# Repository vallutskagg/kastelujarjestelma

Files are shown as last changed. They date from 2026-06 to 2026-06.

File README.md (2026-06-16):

# Watering System

ESP32- ja ESP-IDF-pohjainen automaattinen kastelujärjestelmä. Järjestelmä
mittaa maan kosteutta ja ulkolämpötilaa, tarkkailee vesisäiliön tasoa ja ohjaa
vesipumppua releen kautta. Mittaus- ja ohjaustiedot välitetään MQTT:lla.

Tämä README sisältää kokoamis-, asennus-, kalibrointi-, käyttö- ja
GitHub-ohjeet, joiden avulla toinen käyttäjä voi ottaa projektin käyttöön.

## Sisältö

- [Toimintaperiaate](#toimintaperiaate)
- [Tarvittavat osat](#tarvittavat-osat)
- [Kytkennät](#kytkennät)
- [Ohjelmiston asennus](#ohjelmiston-asennus)
- [Asetukset](#asetukset)
- [Kalibrointi](#kalibrointi)
- [MQTT-käyttö](#mqtt-käyttö)
- [Testaus](#testaus)
- [PCB- ja kotelotiedostot](#pcb--ja-kotelotiedostot)
- [Vianhaku](#vianhaku)

## Toimintaperiaate

ESP32 suorittaa seuraavaa toimintalogiikkaa:

1. Laite käynnistää releen pois päältä, alustaa anturit ja yhdistää 2,4 GHz
   Wi-Fi-verkkoon sekä MQTT-brokeriin.
2. Maankosteusanturista luetaan useita ADC-näytteitä ja niiden keskiarvo.
3. Jos ADC-arvo ylittää kuivuusrajan riittävän monta peräkkäistä kertaa, maa
   tulkitaan kuivaksi.
4. Pumppu käynnistetään vain, jos pumpun ohjaus on sallittu, kastelujen välinen
   turva-aika on kulunut ja säiliöanturi ei ilmoita veden olevan vähissä.
5. Pumppu käy asetetun ajan ja sammuu automaattisesti.
6. DS18B20-lämpötila, maankosteus, säiliön tila ja pumpun tila julkaistaan
   MQTT:lla.
7. Pumppua, mittausta ja kasteluaikaa voi ohjata myös MQTT-komennoilla.

Säiliön tila `LOW` estää sekä automaattisen että manuaalisen pumppauksen.
Tila `UNKNOWN` ei nykyisessä ohjelmassa estä pumppausta. Jos säiliöanturi ei ole
kytketty tai toimii väärin, pumppua saa käyttää vain valvotusti.

Releohjaus on active-low:

- `GPIO26 = HIGH`: rele ja pumppu pois päältä
- `GPIO26 = LOW`: rele ja pumppu päällä

Kastelujen välinen turva-aika tallennetaan vain ESP32:n muistiin. Laitteen
uudelleenkäynnistys nollaa viimeisen kastelun ajan.

## Projektin rakenne

| Polku | Sisältö |
| --- | --- |
| [`main/`](main/) | ESP32-ohjelmiston lähdekoodi ja asetukset |
| [`hardware/pcb/`](hardware/pcb/) | KiCad-projekti ja piirilevyn lähdetiedostot |
| [`hardware/enclosure/`](hardware/enclosure/) | OpenSCAD-kotelomalli |
| [`PCB_OHJE.md`](PCB_OHJE.md) | PCB:n yksityiskohtaiset suunnitteluohjeet |
| [`GITHUB_OHJE.md`](GITHUB_OHJE.md) | Git- ja GitHub-työskentelyohje |
| `pump_test_values_backup_2026-04-10.txt` | Aiemmat pumpun testiasetukset |

## Tarvittavat osat

Pakolliset osat:

- ESP32 DevKit, jota ESP-IDF tukee
- kapasitiivinen maankosteusanturi, analoginen `0-3,0 V` ulostulo
- active-low-yhteensopiva 1-kanavainen 5 V relemoduuli
- 3-5 V DC-vesipumppu ja sopiva letku
- kapasitiivinen säiliön tasoanturi digitaalisella ulostulolla
- virtalähde pumpulle ja releelle
- johdot ja liittimet

Suositellut tai valinnaiset osat:

- DS18B20-lämpötila-anturi
- `4,7 kOhm` vastus DS18B20 DATA-linjan ja `3V3`:n väliin
- LED ja `330 Ohm` sarjavastus säiliön alhaisen tason ilmaisimeksi
- `100 nF` ohituskondensaattorit antureiden syöttöihin
- projektin KiCad-piirilevy ja 3D-tulostettu kotelo

Katso tarkempi komponentti- ja liitinluettelo tiedostosta
[`PCB_OHJE.md`](PCB_OHJE.md).

## Kytkennät

### ESP32-signaalit

| Toiminto | ESP32-pinni | Huomio |
| --- | --- | --- |
| Releen ohjaus | `GPIO26` | Active-low |
| Maankosteusanturin AO | `GPIO34` | ADC1 channel 6, enintään 3,3 V |
| DS18B20 DATA | `GPIO4` | `4,7 kOhm` pull-up vastus `3V3`:een |
| Säiliön tasoanturin signaali | `GPIO27` | Oletuksena HIGH tarkoittaa vettä |
| Säiliön tason LED | `GPIO25` | Oletuksena LED syttyy, kun säiliö on LOW |

### Peruskytkentä

- Kytke ESP32:n, relemoduulin, antureiden ja pumpun virtalähteen maat yhteen.
- Kytke maankosteusanturi `3V3`:een. Älä syötä yli 3,3 V signaalia
  `GPIO34`:aan.
- Kytke DS18B20 `3V3`:een ja lisää DATA-linjalle `4,7 kOhm` pull-up-vastus.
- Kytke relemoduulin `IN` pinniin `GPIO26`.
- Kytke pumpun virtapiiri releen `COM`- ja `NO`-kontaktien kautta.
- Kytke säiliöanturi valmistajan pinijärjestyksen mukaisesti. Tarkista
  johdinvärit ennen virran kytkemistä.

Tarkat netit, liittimet, jännitteet ja PCB-layout-ohjeet ovat tiedostossa
[`PCB_OHJE.md`](PCB_OHJE.md).

## Ohjelmiston asennus

### 1. Asenna työkalut

Tarvitset:

- Git
- Espressif ESP-IDF
- USB-ajurin omalle ESP32-kehityskortille
- datansiirtoa tukevan USB-kaapelin

Windowsissa helpoin tapa on asentaa Espressif IDF Installer ja avata sen
luoma **ESP-IDF PowerShell**, jossa `idf.py` on käytettävissä.

### 2. Lataa projekti

```powershell
git clone https://github.com/vallutskagg/kastelujarjestelma.git
cd kastelujarjestelma
```

### 3. Valitse kohde ja aseta tunnukset

```powershell
idf.py set-target esp32
idf.py menuconfig
```

Avaa valikko **Watering System** ja aseta ainakin:

- `WiFi SSID`
- `WiFi password`
- `MQTT broker URI`
- yksilöllinen `MQTT client id`
- MQTT-käyttäjätunnus ja salasana, jos broker vaatii ne

Wi-Fi- ja MQTT-salaisuudet tallentuvat paikalliseen `sdkconfig`-tiedostoon.
Tiedosto on ohitettu Gitissa, eikä sitä pidä julkaista GitHubiin.

Jos käytät julkista MQTT-brokeria, muuta kaikki MQTT-topic-nimet
yksilöllisiksi. Muuten muut saman brokerin käyttäjät voivat nähdä viestejä tai
lähettää pumppukomentoja.

### 4. Käännä ja siirrä ohjelma

```powershell
idf.py build
idf.py -p COM3 flash monitor
```

Korvaa `COM3` oman ESP32-laitteesi portilla. Sulje sarjamonitori
ESP-IDF:n pikanäppäimellä `Ctrl+]`.

Onnistuneessa käynnistyksessä lokissa näkyy muun muassa Wi-Fi- ja
MQTT-yhteys, antureiden alustus sekä kosteusmittauksia.

## Asetukset

Asetuksia muokataan komennolla `idf.py menuconfig` valikosta
**Watering System**.

| Asetus | Oletus | Merkitys |
| --- | ---: | --- |
| `WATERING_DRY_THRESHOLD` | `3000` | Tämän ylittävä ADC-arvo tulkitaan kuivaksi |
| `WATERING_MOISTURE_WET_ADC` | `1500` | 0 prosentin kuivuuden kalibrointipiste |
| `WATERING_MOISTURE_DRY_ADC` | `3200` | 100 prosentin kuivuuden kalibrointipiste |
| `WATERING_PUMP_ON_MS` | `8000` | Pumpun oletuskäyntiaika millisekunteina |
| `WATERING_CHECK_INTERVAL_MS` | `60000` | Maankosteuden automaattinen mittausväli |
| `WATERING_DRY_CONSECUTIVE_READS` | `3` | Vaaditut peräkkäiset kuivat mittaukset |
| `WATERING_MIN_WATERING_INTERVAL_HOURS` | `72` | Kastelujen välinen turva-aika |
| `WATERING_ADC_SAMPLES` | `8` | Keskiarvoon käytettävien ADC-näytteiden määrä |
| `WATERING_TEMP_READ_INTERVAL_MS` | `10000` | Lämpötilan mittausväli |
| `WATERING_MQTT_CMD_ARM_DELAY_MS` | `5000` | MQTT-komentojen esto yhdistämisen jälkeen |

Ensimmäinen testaus kannattaa tehdä lyhyellä pumpun käyntiajalla ja ilman,
että letku osoittaa kasviin. Aseta lopulliset arvot kasvin, ruukun, pumpun ja
anturin mittausten perusteella.

## Kalibrointi

Maankosteusanturin ADC-arvot riippuvat anturista, maaperästä ja sijoituksesta.
Kalibroi jokainen asennus erikseen:

1. Avaa sarjamonitori komennolla `idf.py monitor`.
2. Mittaa anturi kuivassa tai kuivassa mullassa ja kirjaa lokin
   `Soil ADC avg` -arvo.
3. Mittaa anturi hyvin kosteassa mullassa ja kirjaa arvo.
4. Aseta kuiva arvo kohtaan `WATERING_MOISTURE_DRY_ADC`.
5. Aseta märkä arvo kohtaan `WATERING_MOISTURE_WET_ADC`.
6. Valitse `WATERING_DRY_THRESHOLD` kuivan ja märän arvon väliltä.
7. Testaa usean päivän ajan valvotusti ennen automaattisen kastelun käyttöä.

Tässä projektissa suurempi ADC-arvo tarkoittaa oletuksena kuivempaa maata.
Anturia ei saa upottaa elektroniikkaosan yli.

## MQTT-käyttö

Oletusbroker on vain kehitystä varten `mqtt://broker.hivemq.com`. Omaan
jatkuvaan käyttöön suositellaan salasanalla ja TLS-yhteydellä suojattua
brokeria, esimerkiksi paikallista Mosquitto-palvelinta.

### Julkaistavat topicit

| Topic | Sisältö |
| --- | --- |
| `watering_system/soil` | JSON: kosteus, kuivuusprosentti, lämpötila ja ajat |
| `watering_system/soil/raw` | Maankosteuden ADC-raaka-arvo |
| `watering_system/soil/dry_percent` | Kuivuus `0-100` prosenttia |
| `watering_system/temperature/outdoor_c` | DS18B20-lämpötila Celsius-asteina |
| `watering_system/status/pump_duration_s` | Pumpun aktiivinen käyntiaika |
| `watering_system/status/pump_enable` | `ON` tai `OFF` |
| `watering_system/status/pump_running` | `ON` tai `OFF` |
| `watering_system/status/tank_level` | `FULL`, `LOW` tai `UNKNOWN` |
| `watering_system/status/tank_level_raw` | `1`, `0` tai `-1` |

Esimerkki `watering_system/soil`-viestistä:

```json
{
  "moisture": 2875,
  "dry_percent": 81,
  "temperature_c": 21.50,
  "dry_threshold": 3000,
  "ts": 1781000000,
  "last_watering_ts": 0,
  "last_watering_local": "never"
}
```

### Vastaanotettavat komennot

| Topic | Hyväksytty viesti | Toiminto |
| --- | --- | --- |
| `watering_system/cmd/pump_duration_s` | kokonaisluku, oletuksena `8-20` | Muuttaa pumpun käyntiaikaa |
| `watering_system/cmd/pump_manual` | `RUN`, `ON`, `1` tai `START` | Käynnistää manuaalisen kastelun |
| `watering_system/cmd/pump_enable` | `ON`, `OFF`, `1` tai `0` | Sallii tai estää pumpun |
| `watering_system/cmd/measure_now` | `READ`, `MEASURE`, `ON` tai `1` | Julkaisee uuden kosteusmittauksen |

Esimerkit Mosquitto-työkaluilla:

```powershell
mosquitto_sub -h BROKERIN_OSOITE -t "watering_system/#" -v
mosquitto_pub -h BROKERIN_OSOITE -t "watering_system/cmd/measure_now" -m "READ"
mosquitto_pub -h BROKERIN_OSOITE -t "watering_system/cmd/pump_enable" -m "OFF"
```

Pumpun manuaalinen käynnistys:

```powershell
mosquitto_pub -h BROKERIN_OSOITE -t "watering_system/cmd/pump_manual" -m "RUN"
```

Suorita manuaalinen pumppukomento vain, kun laite ja veden kulku ovat
valvottuja.

## Testaus

Tee testit tässä järjestyksessä:

1. Tarkista kaikki jännitteet ja polariteetit yleismittarilla ilman ESP32:ta.
2. Käynnistä ESP32 ilman pumppua ja tarkista sarjaloki.
3. Tarkista maankosteuden raaka-arvo kuivassa ja kosteassa mullassa.
4. Tarkista DS18B20:n lämpötila.
5. Tarkista, että säiliöanturin tilat `FULL` ja `LOW` vaihtuvat oikein.
6. Tarkista ilman pumppua, että rele kytkeytyy active-low-logiikalla.
7. Testaa pumppu lyhyesti erillään kasvista.
8. Tarkista, että `LOW`-säiliötila estää pumppauksen.
9. Testaa lopuksi automaattikastelu valvotusti.

Releelle on `menuconfig`-valikossa jatkuva self-test-tila. Kun se on käytössä,
normaali kastelulogiikka ei käynnisty. Älä jätä self-test-tilaa päälle
varsinaiseen käyttöön.

## PCB- ja kotelotiedostot

### Esikatselut

#### Schematic

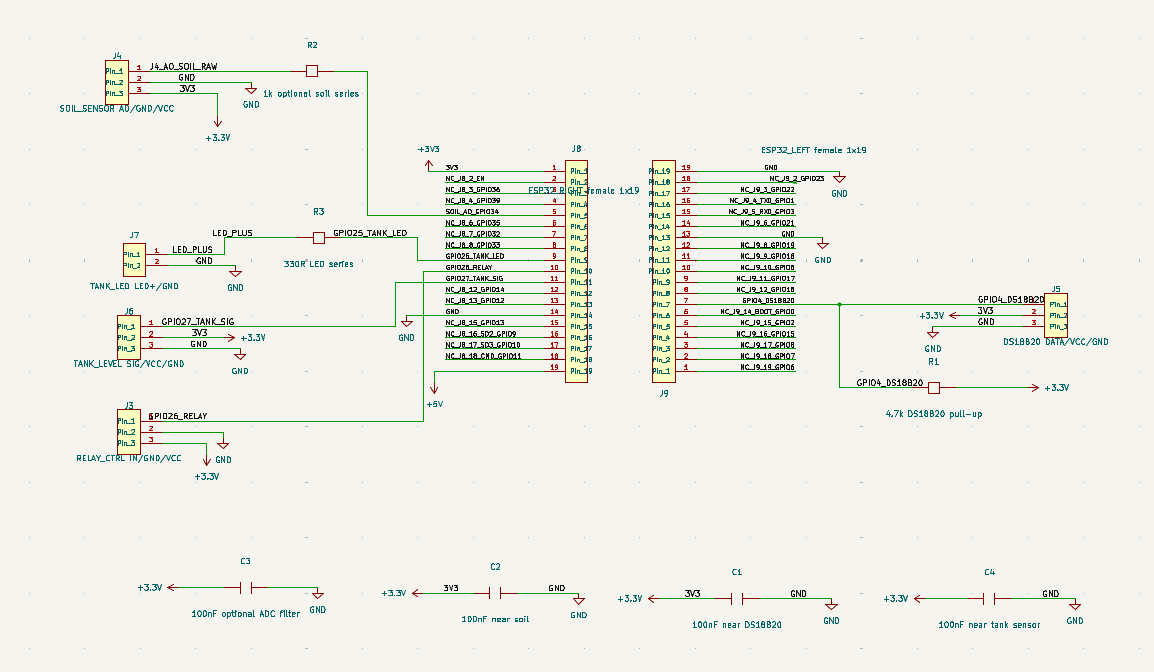
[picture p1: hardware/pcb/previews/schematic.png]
Kastelujärjestelmän schematic


*Kuva 1. Kastelujärjestelmän KiCad-kytkentakaavio. Kaavio sisältää ESP32:n,
maankosteusanturin, DS18B20-lämpötila-anturin, säiliön tasoanturin, LEDin ja
releen ohjausliitännän.*

#### PCB-layout

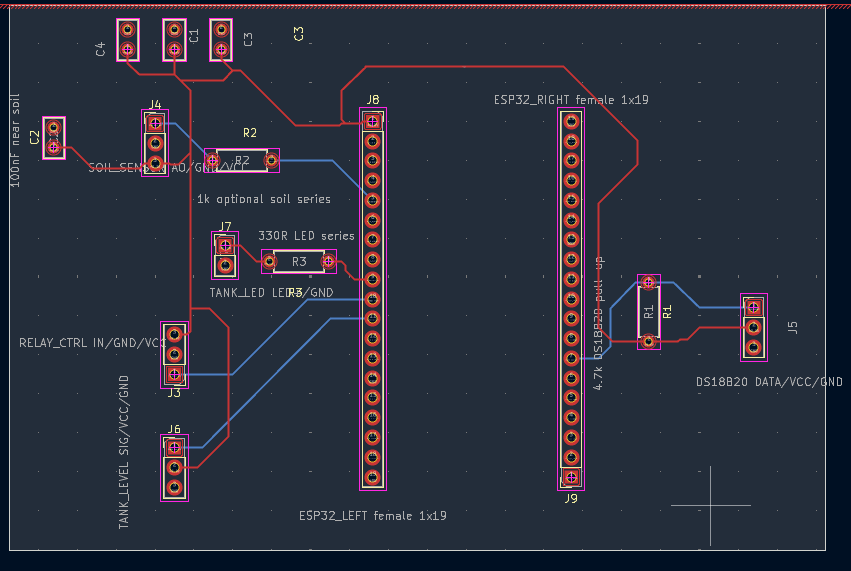
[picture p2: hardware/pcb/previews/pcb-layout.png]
Kastelujärjestelmän PCB-layout


*Kuva 2. Kastelujärjestelmän kaksipuolinen PCB-layout. Punainen kuvaa
etupuolen kuparia ja sininen takapuolen kuparia.*

#### PCB:n 3D-näkymä

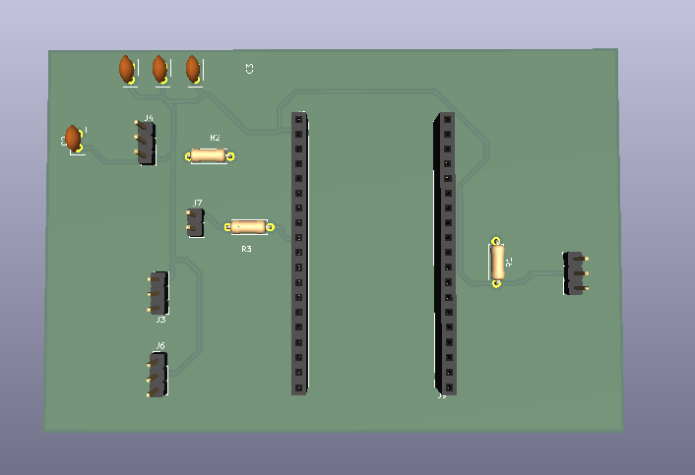
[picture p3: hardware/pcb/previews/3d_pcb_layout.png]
Kastelujärjestelmän PCB 3D-layout


*Kuva 3. KiCadin 3D-layout piirilevystä. Kuvassa näkyvät piirilevyn
komponenttien ja liittimien sijoittelu sekä kuparivetojen reititys.*

#### Kotelon 3D-malli

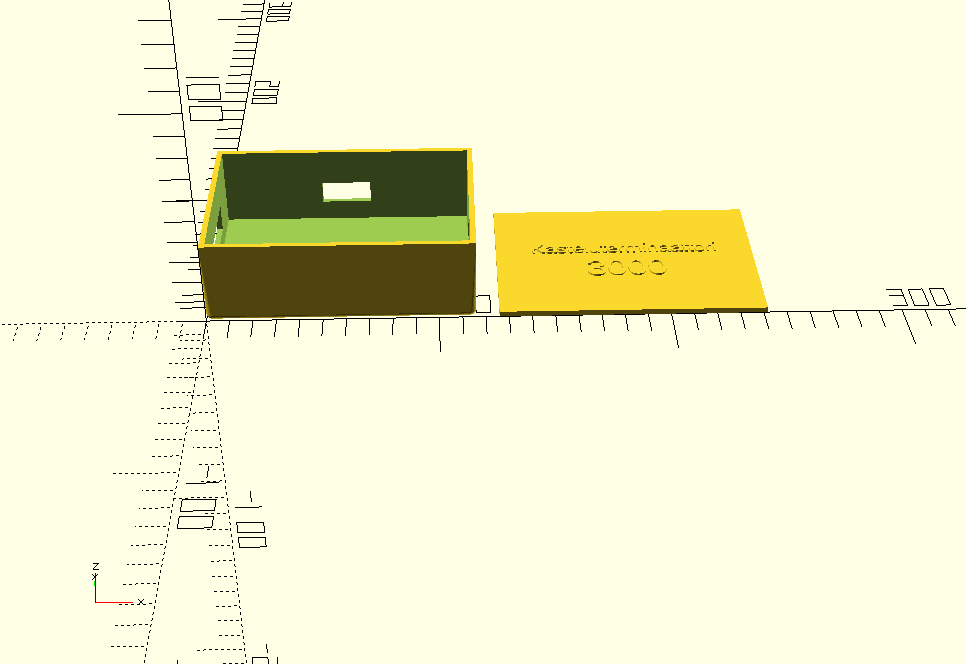
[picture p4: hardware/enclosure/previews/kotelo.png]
Kastelujärjestelmän kotelo


*Kuva 4. OpenSCADilla mallinnettu kotelon pohja ja irrotettava kansi.*

Kuvat näkyvät automaattisesti GitHubissa, kun ne tallennetaan näihin
tiedostopolkuihin ja lisätään Git-versionhallintaan. KiCad-kuvien vientiohjeet
ovat kansiossa [`hardware/pcb/previews/`](hardware/pcb/previews/).

### Mihin tiedostot lisätään

Tallenna muokattavat KiCad-lähdetiedostot tähän kansioon:

```text
hardware/pcb/
```

Nykyiset KiCad-tiedostot:

```text
hardware/pcb/kastelujarjestelma_pcb_ja_schematic/
  irrigation_esp32_J8J9_KUVAN_MUKAINEN.kicad_pro
  irrigation_esp32_J8J9_KUVAN_MUKAINEN.kicad_sch
  irrigation_esp32_J8J9_KUVAN_MUKAINEN.kicad_pcb
  pcb.kicad_pro
  pcb.kicad_pcb
```

Avaa KiCad-projekti ensisijaisesti `.kicad_pro`-tiedostosta. Projektikohtaiset
KiCad-symbolit, footprintit ja kirjastotaulukot kuuluvat samaan kansioon.

Tallenna muokattava OpenSCAD-kotelomalli tähän kansioon:

```text
hardware/enclosure/esp32_kastelu_kotelo.scad
```

Kun tiedostot on lisätty ja julkaistu GitHubiin, käyttäjä voi:

- selata ja ladata lähdetiedostoja kansioista
  [`hardware/pcb/`](hardware/pcb/) ja
  [`hardware/enclosure/`](hardware/enclosure/)
- ladata koko projektin GitHubin **Code > Download ZIP** -toiminnolla
- kloonata projektin komennolla `git clone`
- avata KiCad-lähteet KiCadissa ja `.scad`-tiedoston OpenSCADissa

GitHub näyttää `.scad`-tiedoston tekstinä. KiCad-tiedostoja voi tarkastella
tekstinä, mutta varsinainen schema ja piirilevy avataan KiCadissa.

Jos haluat suunnitelmien olevan helposti tarkasteltavissa suoraan GitHubissa,
vie niistä esikatselukuvat ja tallenna ne versionhallintaan:

```text
hardware/pcb/previews/schematic.png
hardware/pcb/previews/pcb-layout.png
hardware/pcb/previews/3d_pcb_layout.png
hardware/enclosure/previews/kotelo.png
```

PNG- ja SVG-kuvat näkyvät suoraan GitHubin sivulla. Lisää esikatselukuvat
normaalisti Gitiin yhdessä lähdetiedostojen kanssa.

### Valmistus- ja tulostustiedostot

KiCadista generoidut Gerber-, poraus-, BOM- ja pick-and-place-tiedostot
kuuluvat paikallisesti kansioon:

```text
hardware/pcb/generated/
```

OpenSCADista generoidut STL- ja 3MF-tiedostot kuuluvat paikallisesti kansioon:

```text
hardware/enclosure/generated/
```

Nämä `generated/`-kansiot on ohitettu Gitissa. Kun suunnitelma on valmis,
pakkaa valmistustiedostot ZIP-tiedostoiksi ja liitä ne GitHub Releasen
ladattaviksi. Tällä tavalla:

- GitHub-repositorio sisältää aina muokattavat KiCad- ja OpenSCAD-lähteet
- Release sisältää tiettyyn versioon kuuluvat valmiit Gerber- ja STL-tiedostot
- toinen käyttäjä voi joko muokata suunnitelmaa tai ladata valmiin version

Tiedostojen lisääminen Gitiin:

```powershell
git add hardware/pcb hardware/enclosure README.md
git status
git commit -m "Add PCB design and enclosure model"
git push
```

Tarkempi julkaisuohje on tiedostossa [`GITHUB_OHJE.md`](GITHUB_OHJE.md).

## Vianhaku

**`idf.py`-komentoa ei löydy**

Avaa Espressif-asennuksen luoma ESP-IDF PowerShell tai aktivoi ESP-IDF-
ympäristö ennen komentojen suorittamista.

**ESP32 ei yhdistä Wi-Fiin**

Varmista, että verkko on 2,4 GHz ja SSID sekä salasana on asetettu
`idf.py menuconfig` -valikossa.

**MQTT-yhteys ei toimi**

Tarkista brokerin URI, portti, tunnukset, palomuuri ja TLS-asetukset.

**Maankosteusarvo ei muutu**

Tarkista anturin `AO`, `VCC` ja `GND`, mittaa `AO` yleismittarilla ja varmista,
että signaali on kytketty `GPIO34`:aan.

**Pumppu ei käynnisty**

Tarkista MQTT:n `pump_enable`, säiliön tila, releen active-low-logiikka,
pumpun erillinen syöttö ja yhteinen maa.

**Pumppu käynnistyy väärin päin**

Nykyinen ohjelma olettaa active-low-releen. Älä jatka käyttöä ennen kuin releen
logiikka ja turvallinen alkutila on korjattu.

**DS18B20 ei anna lämpötilaa**

Tarkista johdinjärjestys ja `4,7 kOhm` pull-up-vastus DATA-linjan ja `3V3`:n
välillä.

## Turvallisuus

- Testaa laite ja pumppu aina valvotusti ennen automaattista käyttöä.
- Varmista yhteinen maa, oikeat käyttöjännitteet ja riittävä virtalähde.
- Suojaa elektroniikka vedeltä ja suunnittele vuodon seuraukset etukäteen.
- Älä syötä yli 3,3 V jännitettä ESP32:n GPIO-pinneihin.
- Älä kytke 230 V verkkovirtaa tämän projektin releeseen ilman asianmukaista
  sähkösuunnittelua, eristyksiä ja kotelointia.
- Julkisessa MQTT-brokerissa kuka tahansa voi mahdollisesti nähdä tai lähettää
  viestejä. Käytä tuotantokäytössä suojattua brokeria ja yksilöllisiä topic-
  nimiä.

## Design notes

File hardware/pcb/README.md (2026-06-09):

# PCB design status

Nykyiset KiCad-lahdetiedostot:

- `kastelujarjestelma_pcb_ja_schematic/irrigation_esp32_J8J9_KUVAN_MUKAINEN.kicad_pro`
- `kastelujarjestelma_pcb_ja_schematic/irrigation_esp32_J8J9_KUVAN_MUKAINEN.kicad_sch`
- `kastelujarjestelma_pcb_ja_schematic/irrigation_esp32_J8J9_KUVAN_MUKAINEN.kicad_pcb`
- `kastelujarjestelma_pcb_ja_schematic/pcb.kicad_pro`
- `kastelujarjestelma_pcb_ja_schematic/pcb.kicad_pcb`

## Tarkistettu

- KiCad-tiedostomuoto on version 10.0 muodossa.
- PCB:n reunamitta on `105 x 70 mm`.
- Firmware-signaalit ovat PCB:ssa:
  - `GPIO4`: DS18B20
  - `GPIO25`: tankin LED
  - `GPIO26`: rele
  - `GPIO27`: tankin tasoanturi
  - `GPIO34`: maankosteusanturi
- PCB:ssa on kuparivedot ja GND-kuparialueet molemmilla kuparikerroksilla.
- Anturiliittimet `J4-J7` ja ESP32-liittimet `J8/J9` ovat mukana.

## Korjattava ennen PCB:n tilaamista

- Scheman ja PCB:n tiedostonimet eivat vastaa toisiaan.
- Pumpun virtaliittimet `J1`, `J2` ja relekontaktin liitin `J10` puuttuvat
  nykyisesta schemasta ja PCB:sta.
- `J3`-releliittimen pinni 3 on PCB:ssa `+3.3V`. Projektin
  `PCB_OHJE.md` suosittelee WayinTopin 5 V relemoduulille `USB_5V`:a.
  Tarkista kaytetyn relemoduulin vaatima jannite ja korjaa schema seka PCB.
- KiCad ERC ja DRC on ajettava KiCadissa ennen valmistustiedostojen vientia.
- ESP32 DevKitin fyysinen pinijarjestys, rivivali ja USB-liittimen sijainti on
  verrattava juuri kaytettavaan korttiin.

Nykyista PCB:ta ei tule tilata ennen naiden kohtien tarkistamista.

## GitHubiin tuotavat KiCad-tiedostot

Tuo projektiin:

- nykyista schemaa vastaava `.kicad_pro`
- `.kicad_sch`
- `.kicad_pcb`
- BOM-tiedosto, jos haluat osaluettelon ladattavaksi
- `component_placement_top.png` ja `pseudo_3d_render.png`, jos haluat
  lisakuvia GitHubiin
- Gerber ZIP GitHub Releasen liitteeksi, kun PCB on tarkistettu

Ala tuo tavalliseen Git-versionhallintaan:

- `.history/` ja `*-backups/`
- `*.kicad_prl` ja `*.kicad_pro.lck`
- `~*.kicad_pro.lck`
- irrallisia Gerber-kansioita, jos julkaiset Gerber ZIP:n Releasessa
- vanhoja tai eri versioon kuuluvia `.kicad_pro`, `.kicad_sch` ja
  `.kicad_pcb`-tiedostoja

`DRC.rpt`, `report.txt`, pinmap- ja kytkentaohjeet ovat valinnaisia. Tuo ne
vain, jos ne ovat ajan tasalla ja auttavat projektin kayttajaa.

## GitHub-esikatselut

Tallenna schematic-, layout- ja 3D-kuvat kansioon [`previews/`](previews/).
Kansion README sisaltaa kuvien vientiohjeet.

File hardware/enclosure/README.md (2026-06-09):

# Enclosure

Muokattava OpenSCAD-lahde:

- `esp32_kastelu_kotelo.scad`

Mallin PCB-mitta on `105 x 70 mm`, joka vastaa nykyisen KiCad-PCB:n
reunamittaa. Kotelossa on 3 mm sivuvalys PCB:n jokaiselle reunalle.

OpenSCAD-malli kaantyy onnistuneesti. GitHubissa naytettava OpenSCAD-kuva on
[`previews/kotelo.png`](previews/kotelo.png). Kansiossa oleva
`enclosure.png` on erillinen automaattisesti generoitu renderointi.

## Tarkistettava ennen tulostusta

- Kotelossa ei ole viela PCB:n kiinnitystolppia tai ruuvireikia.
- Aukkojen sijainnit on verrattava fyysiseen ESP32-korttiin ja liittimiin.
- Kannen sisahuulen sopivuus riippuu tulostimen toleransseista.
- Tulosta ensin pieni testiversio tai vain sovitukseen tarvittavat osat.

Generoidut STL-tiedostot kuuluvat `generated/`-kansioon, jota ei tallenneta
Git-versionhallintaan. Julkaise tulostusvalmis STL tarvittaessa GitHub
Releasen liitteena.

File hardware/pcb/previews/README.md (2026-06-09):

# PCB preview images

Tallenna GitHubissa naytettavat KiCad-esikatselut tahan kansioon:

```text
schematic.png
pcb-layout.png
3d_pcb_layout.png
```

## Schematic-kuva

1. Avaa `.kicad_sch` KiCad Schematic Editorissa.
2. Suorita ERC ja korjaa virheet.
3. Valitse **File > Plot**.
4. Vie tai ota kuva ja tallenna se nimella `schematic.png`.

Rajaa kuva niin, etta koko kytkentakaavio nakyy selkeasti.

## PCB-layout-kuva

1. Avaa `.kicad_pcb` KiCad PCB Editorissa.
2. Suorita DRC ja korjaa virheet.
3. Valitse **File > Plot**.
4. Nayta ainakin kerrokset `F.Cu`, `B.Cu`, `F.Silkscreen` ja `Edge.Cuts`.
5. Vie tai ota kuva ja tallenna se nimella `pcb-layout.png`.

## PCB:n 3D-kuva

1. Avaa PCB Editorissa **View > 3D Viewer**.
2. Sovita piirilevy nakymaan kokonaan.
3. Valitse 3D Viewerin kuvankaappaus- tai PNG-vientitoiminto.
4. Tallenna kuva nimella `3d_pcb_layout.png`.

Kun kuvat ovat tassa kansiossa, lisaa ne README-tiedostoon:

```markdown
![Schematic](hardware/pcb/previews/schematic.png)
![PCB layout](hardware/pcb/previews/pcb-layout.png)
![PCB 3D layout](hardware/pcb/previews/3d_pcb_layout.png)
```

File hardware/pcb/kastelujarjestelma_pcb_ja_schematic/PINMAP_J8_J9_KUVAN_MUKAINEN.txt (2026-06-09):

ESP32 DevKit 38-pin J8/J9 pinmap - KUVAN MUKAINEN

J8 = vasen rima kuvassa, pin 1 ylhäällä, pin 19 alhaalla:
J8 pin 01: 3V3
J8 pin 02: NC_J8_2_EN
J8 pin 03: NC_J8_3_GPIO36
J8 pin 04: NC_J8_4_GPIO39
J8 pin 05: SOIL_AO_GPIO34
J8 pin 06: NC_J8_6_GPIO35
J8 pin 07: NC_J8_7_GPIO32
J8 pin 08: NC_J8_8_GPIO33
J8 pin 09: GPIO25_TANK_LED
J8 pin 10: GPIO26_RELAY
J8 pin 11: GPIO27_TANK_SIG
J8 pin 12: NC_J8_12_GPIO14
J8 pin 13: NC_J8_13_GPIO12
J8 pin 14: GND
J8 pin 15: NC_J8_15_GPIO13
J8 pin 16: NC_J8_16_SD2_GPIO9
J8 pin 17: NC_J8_17_SD3_GPIO10
J8 pin 18: NC_J8_18_CMD_GPIO11
J8 pin 19: USB_5V

J9 = oikea rima kuvassa, pin 1 ylhäällä, pin 19 alhaalla:
J9 pin 01: GND
J9 pin 02: NC_J9_2_GPIO23
J9 pin 03: NC_J9_3_GPIO22
J9 pin 04: NC_J9_4_TX0_GPIO1
J9 pin 05: NC_J9_5_RX0_GPIO3
J9 pin 06: NC_J9_6_GPIO21
J9 pin 07: GND
J9 pin 08: NC_J9_8_GPIO19
J9 pin 09: NC_J9_9_GPIO18
J9 pin 10: NC_J9_10_GPIO5
J9 pin 11: NC_J9_11_GPIO17
J9 pin 12: NC_J9_12_GPIO16
J9 pin 13: GPIO4_DS18B20
J9 pin 14: NC_J9_14_BOOT_GPIO0
J9 pin 15: NC_J9_15_GPIO2
J9 pin 16: NC_J9_16_GPIO15
J9 pin 17: NC_J9_17_GPIO8
J9 pin 18: NC_J9_18_GPIO7
J9 pin 19: NC_J9_19_GPIO6

Projektin käytetyt kytkennät:
- GPIO26 -> J3 pin1 RELAY IN
- GPIO34 -> R2 -> J4 pin1 SOIL AO
- GPIO4  -> J5 pin1 DS18B20 DATA + R1 4.7k pull-up 3V3
- GPIO27 -> J6 pin1 TANK SIG
- GPIO25 -> R3 330R -> J7 pin1 LED+
- 3V3 -> J4/J5/J6 anturit
- USB_5V -> J3 pin3 relemoduulin VCC
- GND yhteinen kaikkialla

HUOM: tarkista vielä oman fyysisen ESP32 DevKitin pin1-suunta ennen tilausta.

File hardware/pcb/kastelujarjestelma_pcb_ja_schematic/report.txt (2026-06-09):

Info: Processing symbol 'C1:Capacitor_THT:C_Disc_D5.0mm_W2.5mm_P2.50mm'.
Info: Processing symbol 'J5:Connector_PinHeader_2.54mm:PinHeader_1x03_P2.54mm_Vertical'.
Info: Processing symbol 'C2:Capacitor_THT:C_Disc_D5.0mm_W2.5mm_P2.50mm'.
Info: Processing symbol 'C3:Capacitor_THT:C_Disc_D5.0mm_W2.5mm_P2.50mm'.
Info: Processing symbol 'J4:Connector_PinHeader_2.54mm:PinHeader_1x03_P2.54mm_Vertical'.
Info: Processing symbol 'C4:Capacitor_THT:C_Disc_D5.0mm_W2.5mm_P2.50mm'.
Info: Processing symbol 'J2:TerminalBlock_Phoenix:TerminalBlock_Phoenix_MKDS-1,5-2-5.08_1x02_P5.08mm_Horizontal'.
Info: Processing symbol 'J3:Connector_PinHeader_2.54mm:PinHeader_1x03_P2.54mm_Vertical'.
Info: Processing symbol 'J1:TerminalBlock_Phoenix:TerminalBlock_Phoenix_MKDS-1,5-2-5.08_1x02_P5.08mm_Horizontal'.
Info: Processing symbol 'J7:Connector_PinHeader_2.54mm:PinHeader_1x02_P2.54mm_Vertical'.
Info: Processing symbol 'J6:Connector_PinHeader_2.54mm:PinHeader_1x03_P2.54mm_Vertical'.
Info: Processing symbol 'J8:Connector_PinSocket_2.54mm:PinSocket_1x19_P2.54mm_Vertical'.
Info: Processing symbol 'J9:Connector_PinSocket_2.54mm:PinSocket_1x19_P2.54mm_Vertical'.
Info: Processing symbol 'R1:Resistor_THT:R_Axial_DIN0207_L6.3mm_D2.5mm_P7.62mm_Horizontal'.
Info: Processing symbol 'R2:Resistor_THT:R_Axial_DIN0207_L6.3mm_D2.5mm_P7.62mm_Horizontal'.
Info: Processing symbol 'R3:Resistor_THT:R_Axial_DIN0207_L6.3mm_D2.5mm_P7.62mm_Horizontal'.
Updated C1 sheetfile to 'irrigation_esp32_J8J9_KUVAN_MUKAINEN.kicad_sch'.
Add net GND.
Connected C1 pin 2 to GND.
Add net +3.3V.
Connected C1 pin 1 to +3.3V.
Updated C1 unit metadata.
Added C2 (footprint 'Capacitor_THT:C_Disc_D5.0mm_W2.5mm_P2.50mm').
Changed REF** reference designator to C2.
Changed C2 value from C_Disc_D5.0mm_W2.5mm_P2.50mm to 100nF near soil.
Updated C2 symbol association from  to /d6aa60a1-88cd-4455-b2f5-6c455e267b92.
Updated C2 sheetname to '/'.
Updated C2 sheetfile to 'irrigation_esp32_J8J9_KUVAN_MUKAINEN.kicad_sch'.
Connected C2 pin 1 to +3.3V.
Connected C2 pin 2 to GND.
Updated C2 unit metadata.
Added C3 (footprint 'Capacitor_THT:C_Disc_D5.0mm_W2.5mm_P2.50mm').
Changed REF** reference designator to C3.
Changed C3 value from C_Disc_D5.0mm_W2.5mm_P2.50mm to 100nF optional ADC filter.
Updated C3 symbol association from  to /b1b8f8b1-98e2-418a-a2a0-e8dff01e6c67.
Updated C3 sheetname to '/'.
Updated C3 sheetfile to 'irrigation_esp32_J8J9_KUVAN_MUKAINEN.kicad_sch'.
Connected C3 pin 2 to GND.
Connected C3 pin 1 to +3.3V.
Updated C3 unit metadata.
Added C4 (footprint 'Capacitor_THT:C_Disc_D5.0mm_W2.5mm_P2.50mm').
Changed REF** reference designator to C4.
Changed C4 value from C_Disc_D5.0mm_W2.5mm_P2.50mm to 100nF near tank sensor.
Updated C4 symbol association from  to /a61d89f7-e535-439e-95ea-b609ed584d32.
Updated C4 sheetname to '/'.
Updated C4 sheetfile to 'irrigation_esp32_J8J9_KUVAN_MUKAINEN.kicad_sch'.
Connected C4 pin 2 to GND.
Connected C4 pin 1 to +3.3V.
Updated C4 unit metadata.
Added J1 (footprint 'TerminalBlock_Phoenix:TerminalBlock_Phoenix_MKDS-1,5-2-5.08_1x02_P5.08mm_Horizontal').
Changed REF** reference designator to J1.
Changed J1 value from TerminalBlock_Phoenix_MKDS-1,5-2-5.08_1x02_P5.08mm_Horizontal to PUMP_IN 5.08mm.
Updated J1 symbol association from  to /df4fdfdc-345c-4314-85ff-3c7a3cf783d4.
Updated J1 sheetname to '/'.
Updated J1 sheetfile to 'irrigation_esp32_J8J9_KUVAN_MUKAINEN.kicad_sch'.
Connected J1 pin 2 to GND.
Add net +5V.
Connected J1 pin 1 to +5V.
Updated J1 unit metadata.
Added J2 (footprint 'TerminalBlock_Phoenix:TerminalBlock_Phoenix_MKDS-1,5-2-5.08_1x02_P5.08mm_Horizontal').
Changed REF** reference designator to J2.
Changed J2 value from TerminalBlock_Phoenix_MKDS-1,5-2-5.08_1x02_P5.08mm_Horizontal to PUMP_OUT 5.08mm.
Updated J2 symbol association from  to /52a8d773-613a-42f5-aadd-c3646717ac32.
Updated J2 sheetname to '/'.
Updated J2 sheetfile to 'irrigation_esp32_J8J9_KUVAN_MUKAINEN.kicad_sch'.
Add net /PUMP_OUT+.
Connected J2 pin 1 to /PUMP_OUT+.
Connected J2 pin 2 to GND.
Updated J2 unit metadata.
Added J3 (footprint 'Connector_PinHeader_2.54mm:PinHeader_1x03_P2.54mm_Vertical').
Changed REF** reference designator to J3.
Changed J3 value from PinHeader_1x03_P2.54mm_Vertical to RELAY_CTRL IN/GND/VCC.
Updated J3 symbol association from  to /609da12c-0c87-498b-9698-6cff94efed6b.
Updated J3 sheetname to '/'.
Updated J3 sheetfile to 'irrigation_esp32_J8J9_KUVAN_MUKAINEN.kicad_sch'.
Connected J3 pin 3 to +3.3V.
Add net /GPIO26_RELAY.
Connected J3 pin 1 to /GPIO26_RELAY.
Connected J3 pin 2 to GND.
Updated J3 unit metadata.
Added J4 (footprint 'Connector_PinHeader_2.54mm:PinHeader_1x03_P2.54mm_Vertical').
Changed REF** reference designator to J4.
Changed J4 value from PinHeader_1x03_P2.54mm_Vertical to SOIL_SENSOR AO/GND/VCC.
Updated J4 symbol association from  to /e576c336-7a4c-4498-b2e4-e8cac8ef7e0f.
Updated J4 sheetname to '/'.
Updated J4 sheetfile to 'irrigation_esp32_J8J9_KUVAN_MUKAINEN.kicad_sch'.
Connected J4 pin 3 to +3.3V.
Add net /J4_AO_SOIL_RAW.
Connected J4 pin 1 to /J4_AO_SOIL_RAW.
Connected J4 pin 2 to GND.
Updated J4 unit metadata.
Added J5 (footprint 'Connector_PinHeader_2.54mm:PinHeader_1x03_P2.54mm_Vertical').
Changed REF** reference designator to J5.
Changed J5 value from PinHeader_1x03_P2.54mm_Vertical to DS18B20 DATA/VCC/GND.
Updated J5 symbol association from  to /0a8a95e4-5ecc-4cf6-8c68-aa91ce6b42d8.
Updated J5 sheetname to '/'.
Updated J5 sheetfile to 'irrigation_esp32_J8J9_KUVAN_MUKAINEN.kicad_sch'.
Connected J5 pin 2 to +3.3V.
Connected J5 pin 3 to GND.
Add net /GPIO4_DS18B20.
Connected J5 pin 1 to /GPIO4_DS18B20.
Updated J5 unit metadata.
Added J6 (footprint 'Connector_PinHeader_2.54mm:PinHeader_1x03_P2.54mm_Vertical').
Changed REF** reference designator to J6.
Changed J6 value from PinHeader_1x03_P2.54mm_Vertical to TANK_LEVEL SIG/VCC/GND.
Updated J6 symbol association from  to /22901d46-46c6-4b3c-9925-3d0d8888c864.
Updated J6 sheetname to '/'.
Updated J6 sheetfile to 'irrigation_esp32_J8J9_KUVAN_MUKAINEN.kicad_sch'.
Connected J6 pin 3 to GND.
Connected J6 pin 2 to +3.3V.
Add net /GPIO27_TANK_SIG.
Connected J6 pin 1 to /GPIO27_TANK_SIG.
Updated J6 unit metadata.
Added J7 (footprint 'Connector_PinHeader_2.54mm:PinHeader_1x02_P2.54mm_Vertical').
Changed REF** reference designator to J7.
Changed J7 value from PinHeader_1x02_P2.54mm_Vertical to TANK_LED LED+/GND.
Updated J7 symbol association from  to /8a613fd8-4b93-4bad-a11a-ce1e41b0b67c.
Updated J7 sheetname to '/'.
Updated J7 sheetfile to 'irrigation_esp32_J8J9_KUVAN_MUKAINEN.kicad_sch'.
Add net /LED_PLUS.
Connected J7 pin 1 to /LED_PLUS.
Connected J7 pin 2 to GND.
Updated J7 unit metadata.
Added C1 (footprint 'Capacitor_THT:C_Disc_D5.0mm_W2.5mm_P2.50mm').
Added J8 (footprint 'Connector_PinSocket_2.54mm:PinSocket_1x19_P2.54mm_Vertical').
Changed REF** reference designator to J8.
Changed J8 value from PinSocket_1x19_P2.54mm_Vertical to ESP32_LEFT female 1x19.
Updated J8 symbol association from  to /dfe4d59f-4863-4cdd-81cc-1a117c8d2e68.
Updated J8 sheetname to '/'.
Updated J8 sheetfile to 'irrigation_esp32_J8J9_KUVAN_MUKAINEN.kicad_sch'.
Add net /SOIL_AO_GPIO34.
Connected J8 pin 5 to /SOIL_AO_GPIO34.
Add net /NC_J8_15_GPIO13.
Connected J8 pin 15 to /NC_J8_15_GPIO13.
Add net /NC_J8_6_GPIO35.
Connected J8 pin 6 to /NC_J8_6_GPIO35.
Connected J8 pin 1 to +3.3V.
Connected J8 pin 10 to /GPIO26_RELAY.
Add net /NC_J8_7_GPIO32.
Connected J8 pin 7 to /NC_J8_7_GPIO32.
Add net /GPIO25_TANK_LED.
Connected J8 pin 9 to /GPIO25_TANK_LED.
Add net /NC_J8_3_GPIO36.
Connected J8 pin 3 to /NC_J8_3_GPIO36.
Connected J8 pin 14 to GND.
Add net /NC_J8_8_GPIO33.
Connected J8 pin 8 to /NC_J8_8_GPIO33.
Add net /NC_J8_18_CMD_GPIO11.
Connected J8 pin 18 to /NC_J8_18_CMD_GPIO11.
Add net /NC_J8_2_EN.
Connected J8 pin 2 to /NC_J8_2_EN.
Add net /NC_J8_13_GPIO12.
Connected J8 pin 13 to /NC_J8_13_GPIO12.
Connected J8 pin 19 to +5V.
Add net /NC_J8_4_GPIO39.
Connected J8 pin 4 to /NC_J8_4_GPIO39.
Add net /NC_J8_12_GPIO14.
Connected J8 pin 12 to /NC_J8_12_GPIO14.
Add net /NC_J8_17_SD3_GPIO10.
Connected J8 pin 17 to /NC_J8_17_SD3_GPIO10.
Connected J8 pin 11 to /GPIO27_TANK_SIG.
Add net /NC_J8_16_SD2_GPIO9.
Connected J8 pin 16 to /NC_J8_16_SD2_GPIO9.
Updated J8 unit metadata.
Changed REF** reference designator to C1.
Added J9 (footprint 'Connector_PinSocket_2.54mm:PinSocket_1x19_P2.54mm_Vertical').
Changed REF** reference designator to J9.
Changed J9 value from PinSocket_1x19_P2.54mm_Vertical to ESP32_RIGHT female 1x19.
Updated J9 symbol association from  to /8f98fb17-6412-47bc-9ead-b1ee5134a4a6.
Updated J9 sheetname to '/'.
Updated J9 sheetfile to 'irrigation_esp32_J8J9_KUVAN_MUKAINEN.kicad_sch'.
Add net /NC_J9_10_GPIO5.
Connected J9 pin 10 to /NC_J9_10_GPIO5.
Add net /NC_J9_12_GPIO16.
Connected J9 pin 8 to /NC_J9_12_GPIO16.
Add net /NC_J9_15_GPIO2.
Connected J9 pin 5 to /NC_J9_15_GPIO2.
Add net /NC_J9_2_GPIO23.
Changed C1 value from C_Disc_D5.0mm_W2.5mm_P2.50mm to 100nF near DS18B20.
Add net /NC_J9_18_GPIO7.
Connected J9 pin 2 to /NC_J9_18_GPIO7.
Add net /NC_J9_3_GPIO22.
Connected J9 pin 17 to /NC_J9_3_GPIO22.
Add net /NC_J9_16_GPIO15.
Connected J9 pin 4 to /NC_J9_16_GPIO15.
Add net /NC_J9_11_GPIO17.
Connected J9 pin 9 to /NC_J9_11_GPIO17.
Add net /NC_J9_5_RX0_GPIO3.
Connected J9 pin 15 to /NC_J9_5_RX0_GPIO3.
Connected J9 pin 19 to GND.
Add net /NC_J9_19_GPIO6.
Connected J9 pin 1 to /NC_J9_19_GPIO6.
Add net /NC_J9_9_GPIO18.
Connected J9 pin 11 to /NC_J9_9_GPIO18.
Add net /NC_J9_6_GPIO21.
Connected J9 pin 14 to /NC_J9_6_GPIO21.
Add net /NC_J9_8_GPIO19.
Connected J9 pin 12 to /NC_J9_8_GPIO19.
Connected J9 pin 7 to /GPIO4_DS18B20.
Add net /NC_J9_17_GPIO8.
Connected J9 pin 3 to /NC_J9_17_GPIO8.
Connected J9 pin 13 to GND.
Add net /NC_J9_4_TX0_GPIO1.
Connected J9 pin 16 to /NC_J9_4_TX0_GPIO1.
Add net /NC_J9_14_BOOT_GPIO0.
Connected J9 pin 6 to /NC_J9_14_BOOT_GPIO0.
Updated J9 unit metadata.
Connected J9 pin 18 to /NC_J9_2_GPIO23.
Added R1 (footprint 'Resistor_THT:R_Axial_DIN0207_L6.3mm_D2.5mm_P7.62mm_Horizontal').
Changed REF** reference designator to R1.
Changed R1 value from R_Axial_DIN0207_L6.3mm_D2.5mm_P7.62mm_Horizontal to 4.7k DS18B20 pull-up.
Updated R1 symbol association from  to /d8439bb2-c526-4d66-b4a9-43f492052bf1.
Updated R1 sheetname to '/'.
Updated R1 sheetfile to 'irrigation_esp32_J8J9_KUVAN_MUKAINEN.kicad_sch'.
Connected R1 pin 2 to +3.3V.
Connected R1 pin 1 to /GPIO4_DS18B20.
Updated R1 unit metadata.
Updated C1 symbol association from  to /00886970-a28d-493f-ad33-7e46a7a037cf.
Added R2 (footprint 'Resistor_THT:R_Axial_DIN0207_L6.3mm_D2.5mm_P7.62mm_Horizontal').
Changed REF** reference designator to R2.
Changed R2 value from R_Axial_DIN0207_L6.3mm_D2.5mm_P7.62mm_Horizontal to 1k optional soil series.
Updated R2 symbol association from  to /f4022447-6632-4876-98b5-21060c3d75dd.
Updated R2 sheetname to '/'.
Updated R2 sheetfile to 'irrigation_esp32_J8J9_KUVAN_MUKAINEN.kicad_sch'.
Connected R2 pin 2 to /SOIL_AO_GPIO34.
Connected R2 pin 1 to /J4_AO_SOIL_RAW.
Updated R2 unit metadata.
Updated C1 sheetname to '/'.
Added R3 (footprint 'Resistor_THT:R_Axial_DIN0207_L6.3mm_D2.5mm_P7.62mm_Horizontal').
Changed REF** reference designator to R3.
Changed R3 value from R_Axial_DIN0207_L6.3mm_D2.5mm_P7.62mm_Horizontal to 330R LED series.
Updated R3 symbol association from  to /ec21ec55-fa24-439b-9104-3f9167d2eade.
Updated R3 sheetname to '/'.
Updated R3 sheetfile to 'irrigation_esp32_J8J9_KUVAN_MUKAINEN.kicad_sch'.
Connected R3 pin 1 to /GPIO25_TANK_LED.
Connected R3 pin 2 to /LED_PLUS.
Updated R3 unit metadata.

Info: Total warnings: 0, errors: 0.

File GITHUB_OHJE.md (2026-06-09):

# GitHub-ohje

Projektin GitHub-repositorio:

https://github.com/vallutskagg/kastelujarjestelma

## Lataa projekti

```powershell
git clone https://github.com/vallutskagg/kastelujarjestelma.git
cd kastelujarjestelma
```

## Julkaise paikalliset muutokset

Tarkista aina ensin, mita olet julkaisemassa:

```powershell
git status
```

Lisaa muutokset, tee commit ja pushaa:

```powershell
git add .
git commit -m "Kuvaa muutos lyhyesti"
git push
```

`sdkconfig`, `build/`, KiCadin varmuuskopiot, lukitustiedostot ja paikalliset
Gerber-tiedostot on ohitettu `.gitignore`-tiedostossa. Ala lisaa niita
GitHubiin kasin.

## PCB- ja kotelotiedostot

- KiCad-lahteet ovat kansiossa `hardware/pcb/`.
- OpenSCAD-kotelomalli on kansiossa `hardware/enclosure/`.
- GitHubissa naytettavat kuvat ovat `previews/`-kansioissa.
- Julkaise tarkistetut Gerber ZIP- ja STL-tiedostot GitHub Releasen liitteina.

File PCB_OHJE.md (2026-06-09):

# PCB-ohje kastelujarjestelmalle (ESP32 + rele + maankosteus + DS18B20 + tankkitasoanturi + LED)

Tama ohje vastaa nykyista koodia:
- Rele ohjaus: `GPIO26`
- Maankosteus anturi (analog): `GPIO34` (ADC1_CHANNEL_6)
- DS18B20 data: `GPIO4`
- Kapasitiivinen tankkitasoanturi signaali: `GPIO27`
- Tankkitason LED-indikaattori: `GPIO25`

## 1) Tuotetiedot (DS18B20)

- Kaytossa on DS18B20 digitaalinen lampotila-anturi (1-Wire).
- Anturi toimii yksijohtimisella datavaylalla, joten useita DS18B20-antureita voi liittaa rinnakkain samaan DATA-linjaan.
- Suositeltu kayttojannite: `3.0V - 5.5V` (ESP32-projektissa kayta `3V3`).
- Mittausalue: `-55C ... +125C`
- Tarkkuus: noin `+/-0.5C` alueella `-10C ... +85C`
- Resoluutio: `9-12 bit`, oletus `12 bit`

DS18B20 johdinvarit toimittajan tekstin mukaan:
- `RED -> VCC`
- `GREEN -> DATA`
- `YELLOW -> GND`

WayinTop-kit (tuotekuvaus, tiivistetty):
- Tarkoitus: automaattinen kasvien kastelu maankosteuden perusteella.
- Paketti sisaltaa: kapasitiivinen maankosteusanturi, 1ch 5V relemoduuli, mini vesipumppu, 1 m vinyyliletku.
- Toimintaperiaate: kun maankosteus laskee, ohjaus kaynnistaa pumpun releen kautta.

WayinTop-osien speksit:
- Kapasitiivinen maankosteusanturi:
- Kayttojannite `3.3-5.5VDC`
- Analoginen ulostulo `0-3.0VDC`
- Liitin `PH2.54-3P`
- Koko `98 x 23 mm`
- Pinnit `AO`, `GND`, `VCC`
- 1ch relemoduuli:
- `VCC` = 5V syotto releelle
- `GND` = maa
- Mini pumppu:
- Kayttojannite `3-5VDC`
- Ulosmeno OD `7.5 mm`, ID `4.5 mm`
- Sisaanmeno `5 mm`
- Harjaton DC-rakenne (magneettiohjaus)
- Arvioitu jatkuva kayttoika noin `300 h`
- Vinyyliletku:
- Materiaali `PVC`
- Sisahalkaisija noin `5.54 mm`
- Ulkohalkaisija noin `8.20 mm`
- Pituus `100 cm`

## 2) Turvallisuus ja varoitukset

- Ala ylita syottojannitetta `5.5V`.
- Varmista oikea polariteetti (`VCC` ja `GND` oikein). Vaara kytkenta voi rikkoa anturin.
- Vaikka anturiprobe on kosteudelta suojattu, sita ei suositella jatkuvaan pysyvaan upotukseen vaikeissa olosuhteissa.
- Yhteinen maa (`GND`) on pakollinen: ESP32 + rele + kaikki anturit.
- Jos jokin anturi antaa `5V` signaalin, ala kytke sita suoraan ESP32 GPIO:hon. Kayta jannitejakoa tai level shifteria.
- Jos ohjaat verkkovirtaa (230VAC), tee sille erillinen turvallinen suunnittelu.
- Lue kaytto-ohje ennen asennusta ja varmista, ettei kastelujarjestelma voi aiheuttaa vuotovahinkoa.
- Asenna maankosteusanturi varovasti, jotta anturi ja johdot eivat vaurioidu.

## 3) 3.3V virtastrategia (tama projekti)

Tassa projektissa logiikkapuoli suunnitellaan `3.3V`:lle:
- ESP32: `3V3`
- DS18B20: `3V3`
- Kapasitiivinen maankosteusanturi: `3V3` (anturi tukee 3.3-5.5V)
- Tankkitasoanturi: ensisijaisesti `3V3` (tarkista oma anturiversio)

Rele ja pumppu:
- WayinTopin valmis 1-kanavainen relemoduuli on tyypillisesti `5V` kelalla.
- Relemoduulin syotto otetaan USB:n `5V` linjasta (`USB_5V` / ESP32 DevKit `5V`/`VBUS` pinni).
- Mini pumppu toimii alueella `3-5V`; voit kayttaa `3.3V` tai erillista `5V` syottoa virta- ja tuottovaatimusten mukaan.
- Muut anturit ja logiikka pidetaan `3.3V` kiskossa.
- Kaikissa tapauksissa `GND` on yhteinen.

## 4) Kytkenta (netit)

Nimea verkot (net labels) selkeasti:
- `3V3`
- `USB_5V` (USB:sta tuleva 5V releelle)
- `5V_PUMP` (valinnainen, jos pumppua ajetaan 5V:lla)
- `GND`
- `RELAY_IN_GPIO26`
- `SOIL_AO_GPIO34`
- `DS18B20_DQ_GPIO4`
- `TANK_LEVEL_SIG_GPIO27`
- `TANK_LED_GPIO25`
- `PUMP_SUPPLY+`
- `PUMP_SUPPLY-`
- `PUMP_OUT+`
- `PUMP_OUT-`

Kytke:
- ESP32 `GPIO26` -> relemoduulin `IN`
- ESP32 `GPIO34` -> maankosteusanturin `AO`
- ESP32 `GPIO4` -> DS18B20 `DATA`
- ESP32 `GPIO27` -> tankkianturin `SIGNAL`
- ESP32 `GPIO25` -> LED anodi sarjavastuksen kautta (esim. 330R), LED katodi -> `GND`
- DS18B20 `VCC` -> `3V3`
- DS18B20 `GND` -> `GND`
- `4.7k` vastus DS18B20 `DATA <-> 3V3` (pakollinen)
- Maankosteusanturi `VCC` -> `3V3`
- Maankosteusanturi `GND` -> `GND`
- Tankkitasoanturi:
- `RED -> VCC`
- `BLACK -> GND`
- `YELLOW -> SIGNAL (GPIO27)`
- Relemoduulin `GND` -> `GND`
- Relemoduulin `VCC` -> `USB_5V` (WayinTop 1ch 5V relemoduuli)

Pumpun tehopuoli releen kautta:
- `PUMP_SUPPLY+` (`3.3V` tai `5V_PUMP`) -> rele `COM`
- rele `NO` -> `PUMP_OUT+` (pumpun plus)
- `PUMP_OUT-` -> `PUMP_SUPPLY-`

## 5) Kaytto-ohje (DS18B20)

1. Kytke probe adapteriin johdinvarien mukaan.
2. Tarkista aina moduulin oma silkkipainatus ennen virtojen kytkentaa.
3. Jos kaytat Arduino IDE:ta, kirjastot ovat `OneWire` ja `DallasTemperature`.
4. Oletusresoluutio on 12-bit. Tarvittaessa voit pienentaa resoluutiota nopeampaa mittausta varten.

## 6) Liittimet PCB:lle (samat tyylit kuin kuvassa)

Pakollinen suunnittelusaanto:
- Jokaiselle laitteelle tulee oma erillinen liitin (ei jaettuja anturiliittimia).

- J1: `POWER_IN` 2-pin ruuviliitin (pumpun syotto), suositus `5.08 mm` jako
- J2: `PUMP_OUT` 2-pin ruuviliitin (pumppu), suositus `5.08 mm` jako
- J3: `RELAY_CTRL` 1x3 2.54mm pin header (`IN`, `GND`, `VCC`) kuten kuvan relemoduulissa (Dupont-yhteensopiva)
- J4: `SOIL_SENSOR` 1x3 2.54mm pin header (`AO`, `GND`, `VCC`) yhteensopiva kuvan anturin mukana tulevan kaapelin kanssa
- J5: `DS18B20` 1x3 2.54mm pin header (`DATA`, `VCC`, `GND`) DS18B20 adapterimoduulin signaalipuolelle
- J6: `TANK_LEVEL_SENSOR` 1x3 2.54mm pin header (`SIG`, `VCC`, `GND`) sailioanturin 3-johtimiselle kaapelille
- J7: `TANK_LED` 2-pin liitin (`LED+`, `GND`), suositus 2.54mm pin header
- J8/J9: ESP32-liitannat (devkit-headerit tai suora moduuli footprint)
- J10 (valinnainen): `RELAY_LOAD` 3-pin ruuviliitin (`NC`, `COM`, `NO`) jos relepiiri tehdaan suoraan omalle PCB:lle

Laitekohtainen liitinjako:
- Pumppu -> `J2` (`PUMP_OUT+`, `PUMP_OUT-`)
- Relemoduulin ohjaus -> `J3` (`IN`, `GND`, `VCC`)
- Maankosteusanturi -> `J4` (`AO`, `GND`, `VCC`)
- DS18B20 lampotila-anturi -> `J5` (`DATA`, `VCC`, `GND`)
- Sailio/tankkitasoanturi -> `J6` (`SIG`, `VCC`, `GND`)
- Tankkitason LED -> `J7` (`LED+`, `GND`)

Kuvien osat -> PCB-liitin (suora vastaavuus):
- DS18B20 probe + adapterimoduuli (kuva 1): adapterin 3-pin ohjausliitaanta -> `J5` (2.54mm, Dupont)
- Sailioanturi 3-johtimisella johdolla (kuva 2) -> `J6` (2.54mm, Dupont)
- Kapasitiivinen maankosteusanturi v1.2 (kuva 3) -> `J4` (2.54mm, Dupont / PH2.54-3P kaapeli)
- 1ch relemoduuli (kuva 3): ohjaus `IN/GND/VCC` -> `J3`, kuorma johdetaan moduulin omaan ruuviliittimeen

Releen toteutusvaihtoehdot:
- Vaihtoehto A (helpoin): kayta valmista 1ch 5V relemoduulia johdoilla (`IN/GND/VCC` + moduulin oma ruuviliitin kuormalle).
- Vaihtoehto B (siistein): tuo relepiiri suoraan emolevylle, mutta pidetaan samat ulkoliittimet kuin kuvassa: 1x3 ohjausheader + 3-pin ruuviliitin kuormalle.

## 7) ESP32 kokonaan piirilevylle (pinneineen)

Kuvan mukaisessa ratkaisussa ESP32-DevKit tulee suoraan emolevylle omilla pinneillaan:
- Kayta emolevylla kahta naarasrimaa (female header), joihin ESP32 DevKit painetaan.
- Yleisessa 38-pin DevKitissa: `2 x 19` pin, jako `2.54 mm`, rivien vali tyypillisesti `25.4 mm` (center-to-center).
- Tee silkkipainatukseen selkea merkinta: `USB`-paaty, `EN`, `BOOT`, `3V3`, `GND`.
- Jata USB-liittimen eteen mekaaninen vapaa tila, jotta kaapeli mahtuu paikalleen.
- Ala sijoita korkeita komponentteja EN/BOOT-painikkeiden viereen.
- Lukitse yksi tarkka ESP32-boardimalli ennen tilausta (esim. sama 38-pin malli kuin kuvassa), koska 30-pin/38-pin versiot eivat ole keskenaan suoraan yhteensopivia.

Kaytannon suositus:
- J8: `ESP32_LEFT` 1x19 female header
- J9: `ESP32_RIGHT` 1x19 female header
- Pinijarjestys tehdaan suoraan valitun DevKitin pinoutin mukaan.

## 8) Komponentit

- R1: `4.7k` (DS18B20 pull-up, DATA->3V3)
- R3: `330R` (LED sarjavastus GPIO25 -> LED+)
- C1: `100nF` DS18B20 liittimen lahelle (`VCC`->`GND`)
- C2: `100nF` maankosteusanturin liittimen lahelle (`VCC`->`GND`)
- C4: `100nF` tankkitasoanturin liittimen lahelle (`VCC`->`GND`)
- (Valinnainen) R2: `1k` sarjaan `SOIL_AO_GPIO34`
- (Valinnainen) C3: `100nF` `SOIL_AO_GPIO34` -> `GND` kohinan suodatukseen

WayinTop-kitista huomioitavat lisakomponentit:
- Relemoduuli 5V (jos kaytetaan valmista moduulia)
- Mini DC-pumppu `3-5V`
- PVC-letku `ID noin 5.54 mm`, `OD noin 8.20 mm`, pituus `1 m`

## 9) Layout-ohjeet

- Pida ADC-linja (`SOIL_AO_GPIO34`) kaukana releen ja pumpun tehopoluista.
- Tee yhtenainen GND-taso (ground plane).
- Reitita DS18B20 data lyhyena ja pida `4.7k` vastus lahella ESP32:ta.
- Jata ESP32-moduulin antennin alueen alle ja eteen kupariton keepout (ei kuparia eika tasoja antennin alle).
- Releen kontaktien ja logiikan valiin jata etaisyytta (vahin 2-3 mm DC-jarjestelmassa).
- Kayta pumpun virralle leveampia johtimia:
- signaalit: `0.25 mm`
- 3V3/5V: `0.5 mm`
- pumppulinja: `1.5-2.0 mm` (virran mukaan)

## 10) Mekaaniset tiedot (kuvan anturi)

Kuvan perusteella 3-johtimisen anturin mekaaniset mitat:
- Leveys noin `21 mm`
- Korkeus noin `24.1 mm`
- Kiinnitysreikien halkaisija noin `3 mm`
- Kaapeli: `UL2464 28#3 core`
- Johtimet ilman liitinta, kuorinta noin `5 mm`

Johdinvarit kuvan mukaan:
- `RED -> VCC`
- `BLACK -> GND`
- `YELLOW -> SIGNAL OUTPUT`

## 11) Huolto, varastointi, kierratys

- Pyri valttamaan jyrkkia taivutuksia ja johtoon kohdistuvaa vetoa.
- Sailuta kuivassa, kun laite ei ole kaytossa.
- Kosteissa olosuhteissa tarkista anturin metalliosat saannollisesti hapettumisen varalta.
- Ala havita elektroniikkaa sekajatteeseen, vaan toimita e-jatekierratykseen.

## 12) Firmware-vastaavuus (tarkeat asetukset)

Nykyiset toivotut asetukset:
- `CONFIG_WATERING_CHECK_INTERVAL_MS=3600000` (kosteus 1 h)
- `CONFIG_WATERING_TEMP_READ_INTERVAL_MS=1800000` (lampotila 30 min)
- `CONFIG_WATERING_DRY_THRESHOLD=2800`
- `CONFIG_WATERING_PUMP_ON_MS=8000` (oletuskastelu 8 s)
- `CONFIG_WATERING_PUMP_DURATION_MIN_S=8` (MQTT-saadon minimi 8 s)
- `CONFIG_WATERING_LEVEL_SENSOR_GPIO=27`
- `CONFIG_WATERING_LEVEL_LED_GPIO=25`

Jos vaihdat pinneja PCB:ssa, paivita:
- `CONFIG_WATERING_TEMP_GPIO`
- `CONFIG_WATERING_LEVEL_SENSOR_GPIO`
- `CONFIG_WATERING_LEVEL_LED_GPIO`
- `RELAY_GPIO` (main.c)
- `SOIL_CHANNEL` (main.c, ADC-kanava vastaa valittua GPIO:ta)

MQTT status -topicit tankkitasolle ja LEDille:
- `watering_system/status/tank_level` -> `FULL` / `LOW` / `UNKNOWN`
- `watering_system/status/tank_level_raw` -> `1` / `0` / `-1`

LED toimii paikallisena indikaattorina:
- LED syttyy, kun tankin tila on `LOW` (vetta ei ole riittavasti).

## 13) Ennen tilausta (checklist)

- Tarkista liittimien pinijarjestys silkkipainatuksesta.
- Tarkista, etta pumpulla, releella, maankosteusanturilla, DS18B20:lla ja sailioanturilla on kaikilla oma liitin.
- Tarkista, etta logiikkakiskot ovat `3V3` (ESP32, DS18B20, maankosteusanturi).
- Varmista, etta relemoduulin 5V syotto tulee USB-linjasta (`USB_5V`) ja etta `GND` on yhteinen.
- Tarkista ESP32 DevKitin tarkka pinimaara (30/38) ja mittaa rivivali tyontomitalla ennen PCB-tilausta.
- Varmista, etta USB-kaapeli mahtuu kiinni kun ESP32 on asennettuna emolevylle.
- Tarkista DS18B20 johdinjarjestys juuri omasta anturierasta.
- Tarkista erikseen tankkitasoanturin johdinjarjestys (kuvan mukaan RED/BLACK/YELLOW).
- Varmista relemoduulin triggeritaso (active-low sopii nykyiseen koodiin).
- Tee ensin prototyyppi (1 kpl), testaa ja vasta sitten isompi sarja.

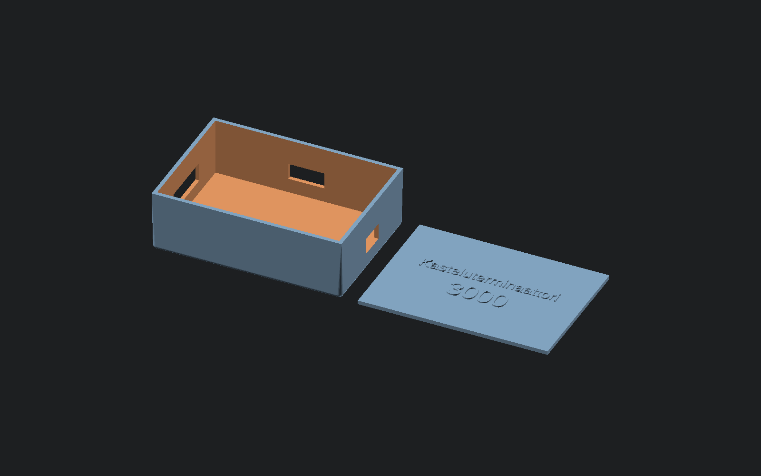
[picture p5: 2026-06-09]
hardware/enclosure/previews/enclosure.png

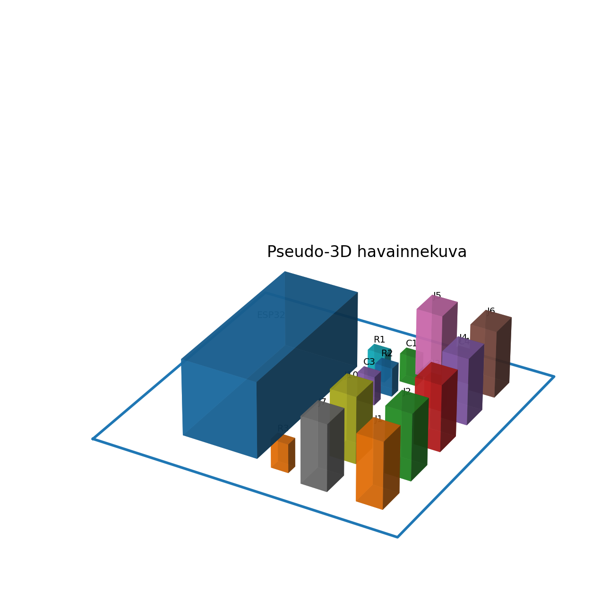
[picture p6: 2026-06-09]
hardware/pcb/kastelujarjestelma_pcb_ja_schematic/pseudo_3d_render.png

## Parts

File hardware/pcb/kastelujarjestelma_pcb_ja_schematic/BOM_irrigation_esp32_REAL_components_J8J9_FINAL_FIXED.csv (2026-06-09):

Reference | Qty | Value | Footprint | Notes
J8,J9 | 2 | 1x19 female header, 2.54mm | PinHeader_1x19_P2.54mm | ESP32 DevKit socket headers, 25.4 mm row spacing on PCB
J1 | 1 | 2-pin screw terminal 5.08mm | TerminalBlock_1x02_P5.08mm | POWER_IN / pump supply
J2 | 1 | 2-pin screw terminal 5.08mm | TerminalBlock_1x02_P5.08mm | PUMP_OUT
J3 | 1 | 1x3 pin header 2.54mm | PinHeader_1x03_P2.54mm | Relay module IN/GND/VCC, VCC=USB_5V
J4 | 1 | 1x3 pin header 2.54mm | PinHeader_1x03_P2.54mm | SOIL_SENSOR: pin1 AO, pin2 GND, pin3 3V3
J5 | 1 | 1x3 pin header 2.54mm | PinHeader_1x03_P2.54mm | DS18B20: DATA/VCC/GND
J6 | 1 | 1x3 pin header 2.54mm | PinHeader_1x03_P2.54mm | Tank level sensor: SIG/VCC/GND
J7 | 1 | 1x2 pin header 2.54mm | PinHeader_1x02_P2.54mm | Tank LED LED+/GND
J10 | 1 | 3-pin screw terminal 5.08mm | TerminalBlock_1x03_P5.08mm | Optional relay load NC/COM/NO
R1 | 1 | 4.7k | R_Axial_DIN0207_P7.62mm | DS18B20 pull-up DATA to 3V3
R2 | 1 | 1k optional | R_Axial_DIN0207_P7.62mm | Series resistor: J4 AO to GPIO34
R3 | 1 | 330R | R_Axial_DIN0207_P7.62mm | LED series resistor
C1,C2,C4 | 3 | 100nF | C_Disc_D5.0mm_P2.50mm | Decoupling near DS18B20, soil, tank connectors
C3 | 1 | 100nF optional | C_Disc_D5.0mm_P2.50mm | ADC filter: GPIO34 to GND

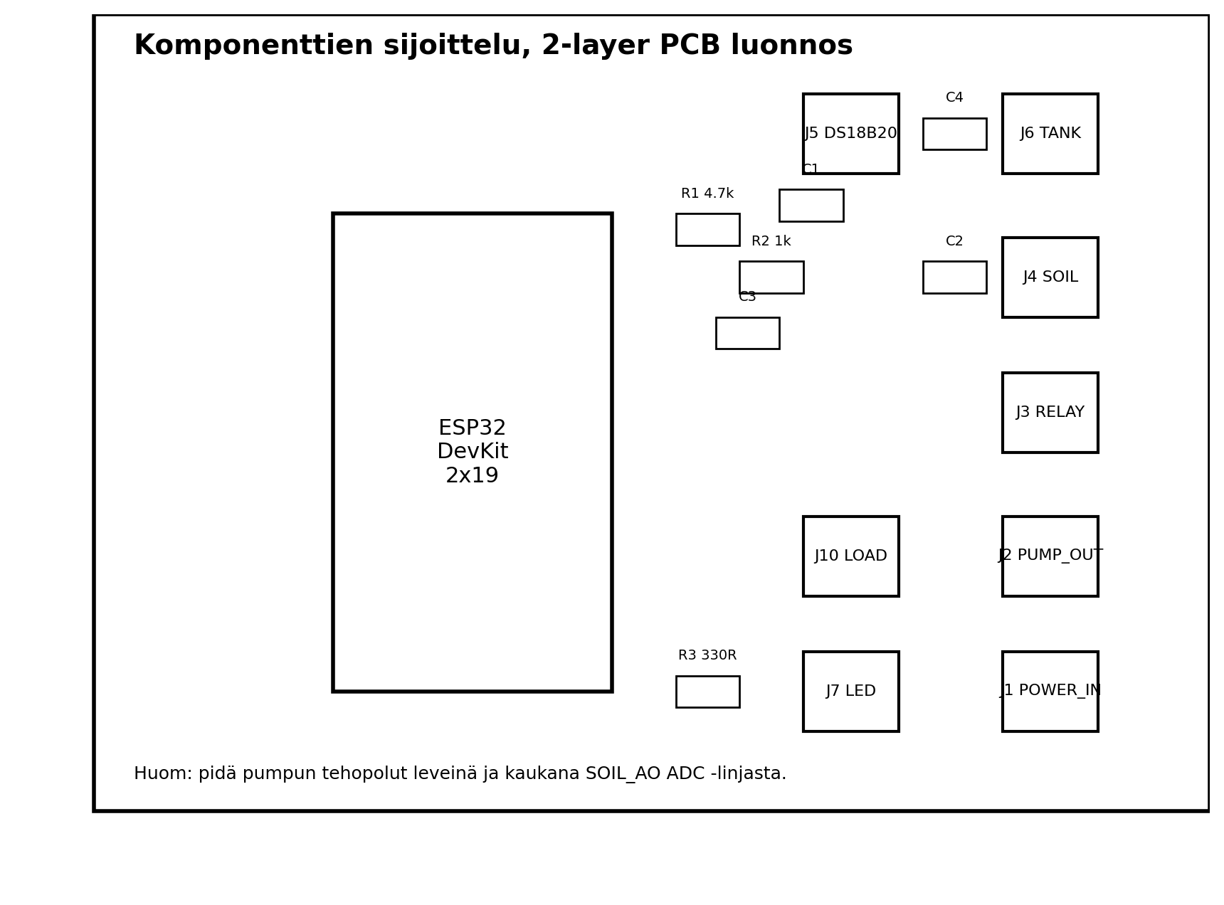
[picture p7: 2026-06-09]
hardware/pcb/kastelujarjestelma_pcb_ja_schematic/component_placement_top.png

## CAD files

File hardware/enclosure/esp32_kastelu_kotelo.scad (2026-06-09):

// ESP32 kastelujarjestelman PCB-kotelo
// PCB koko: 105 x 70 mm

$fn = 48;

pcb_x = 105;
pcb_y = 70;

clearance = 3;
wall = 2.4;
bottom = 2.4;
lid_thickness = 2.4;

inner_x = pcb_x + clearance * 2;
inner_y = pcb_y + clearance * 2;
inner_z = 35;

outer_x = inner_x + wall * 2;
outer_y = inner_y + wall * 2;
outer_z = inner_z + bottom;

usb_cut_w = 16;
usb_cut_h = 10;
side_slot_w = 34;
side_slot_h = 12;

part = "both";

module rounded_box(size=[10,10,10], r=2) {
    hull() {
        for (x=[r, size[0]-r])
        for (y=[r, size[1]-r])
        for (z=[r, size[2]-r])
            translate([x,y,z]) sphere(r=r);
    }
}

module base_shell() {

    difference() {

        // Ulkokuori
        hull() {

            // Pohjan pyöristetyt kulmat
            translate([2.5, 2.5, 2.5])
                sphere(r=2.5);

            translate([outer_x-2.5, 2.5, 2.5])
                sphere(r=2.5);

            translate([2.5, outer_y-2.5, 2.5])
                sphere(r=2.5);

            translate([outer_x-2.5, outer_y-2.5, 2.5])
                sphere(r=2.5);

            // Yläosa suorana
            translate([0,0,outer_z-0.1])
                cube([outer_x, outer_y, 0.1]);
        }

        // Sisäontelo
        translate([wall, wall, bottom])
            cube([inner_x, inner_y, inner_z + 1]);

        // USB-aukko
        translate([outer_x-wall-0.1, outer_y/2 - usb_cut_w/2, bottom + 8])
            cube([wall+0.3, usb_cut_w, usb_cut_h]);

        // Sivuaukko
        translate([-0.1, outer_y/2 - side_slot_w/2, bottom + 8])
            cube([wall+0.3, side_slot_w, side_slot_h]);

        // Johtoaukko
        translate([outer_x/2 - 11, outer_y-wall-0.1, bottom + 9])
            cube([22, wall+0.3, 10]);
    }
}

module base() {
    base_shell();
}

module lid() {

    union() {

        // Kannen peruslevy
        cube([outer_x, outer_y, lid_thickness]);

        // Kohoteksti
        translate([outer_x/2, outer_y/2 + 8, lid_thickness - 0.1])
            linear_extrude(height = 0.9)
                text("Kasteluterminaattori",
                     size = 7,
                     halign = "center",
                     valign = "center",
                     font = "Liberation Sans");

        // 3000-teksti
        translate([outer_x/2, outer_y/2 - 8, lid_thickness - 0.1])
            linear_extrude(height = 0.9)
                text("3000",
                     size = 12,
                     halign = "center",
                     valign = "center",
                     font = "Liberation Sans");

        // Sisähuuli
        translate([wall+1.0, wall+1.0, -2.5])
    difference() {

        cube([inner_x-2.0, inner_y-2.0, 2.7]);

        translate([2.0,2.0,-0.1])
        cube([inner_x-6.0, inner_y-6.0, 2.9]);
}
    }
}

if (part == "base") {
    base();
} else if (part == "lid") {
    lid();
} else {
    base();
    translate([outer_x + 10, 0, 0])
        lid();
}

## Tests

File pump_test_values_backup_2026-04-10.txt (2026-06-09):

# Pump test backup
# Created: 2026-04-10
CONFIG_WATERING_DRY_THRESHOLD=3300
CONFIG_WATERING_PUMP_ON_MS=3000
CONFIG_WATERING_CHECK_INTERVAL_MS=1800000
CONFIG_WATERING_DRY_CONSECUTIVE_READS=6
CONFIG_WATERING_MIN_WATERING_INTERVAL_HOURS=72
CONFIG_WATERING_ADC_SAMPLES=8

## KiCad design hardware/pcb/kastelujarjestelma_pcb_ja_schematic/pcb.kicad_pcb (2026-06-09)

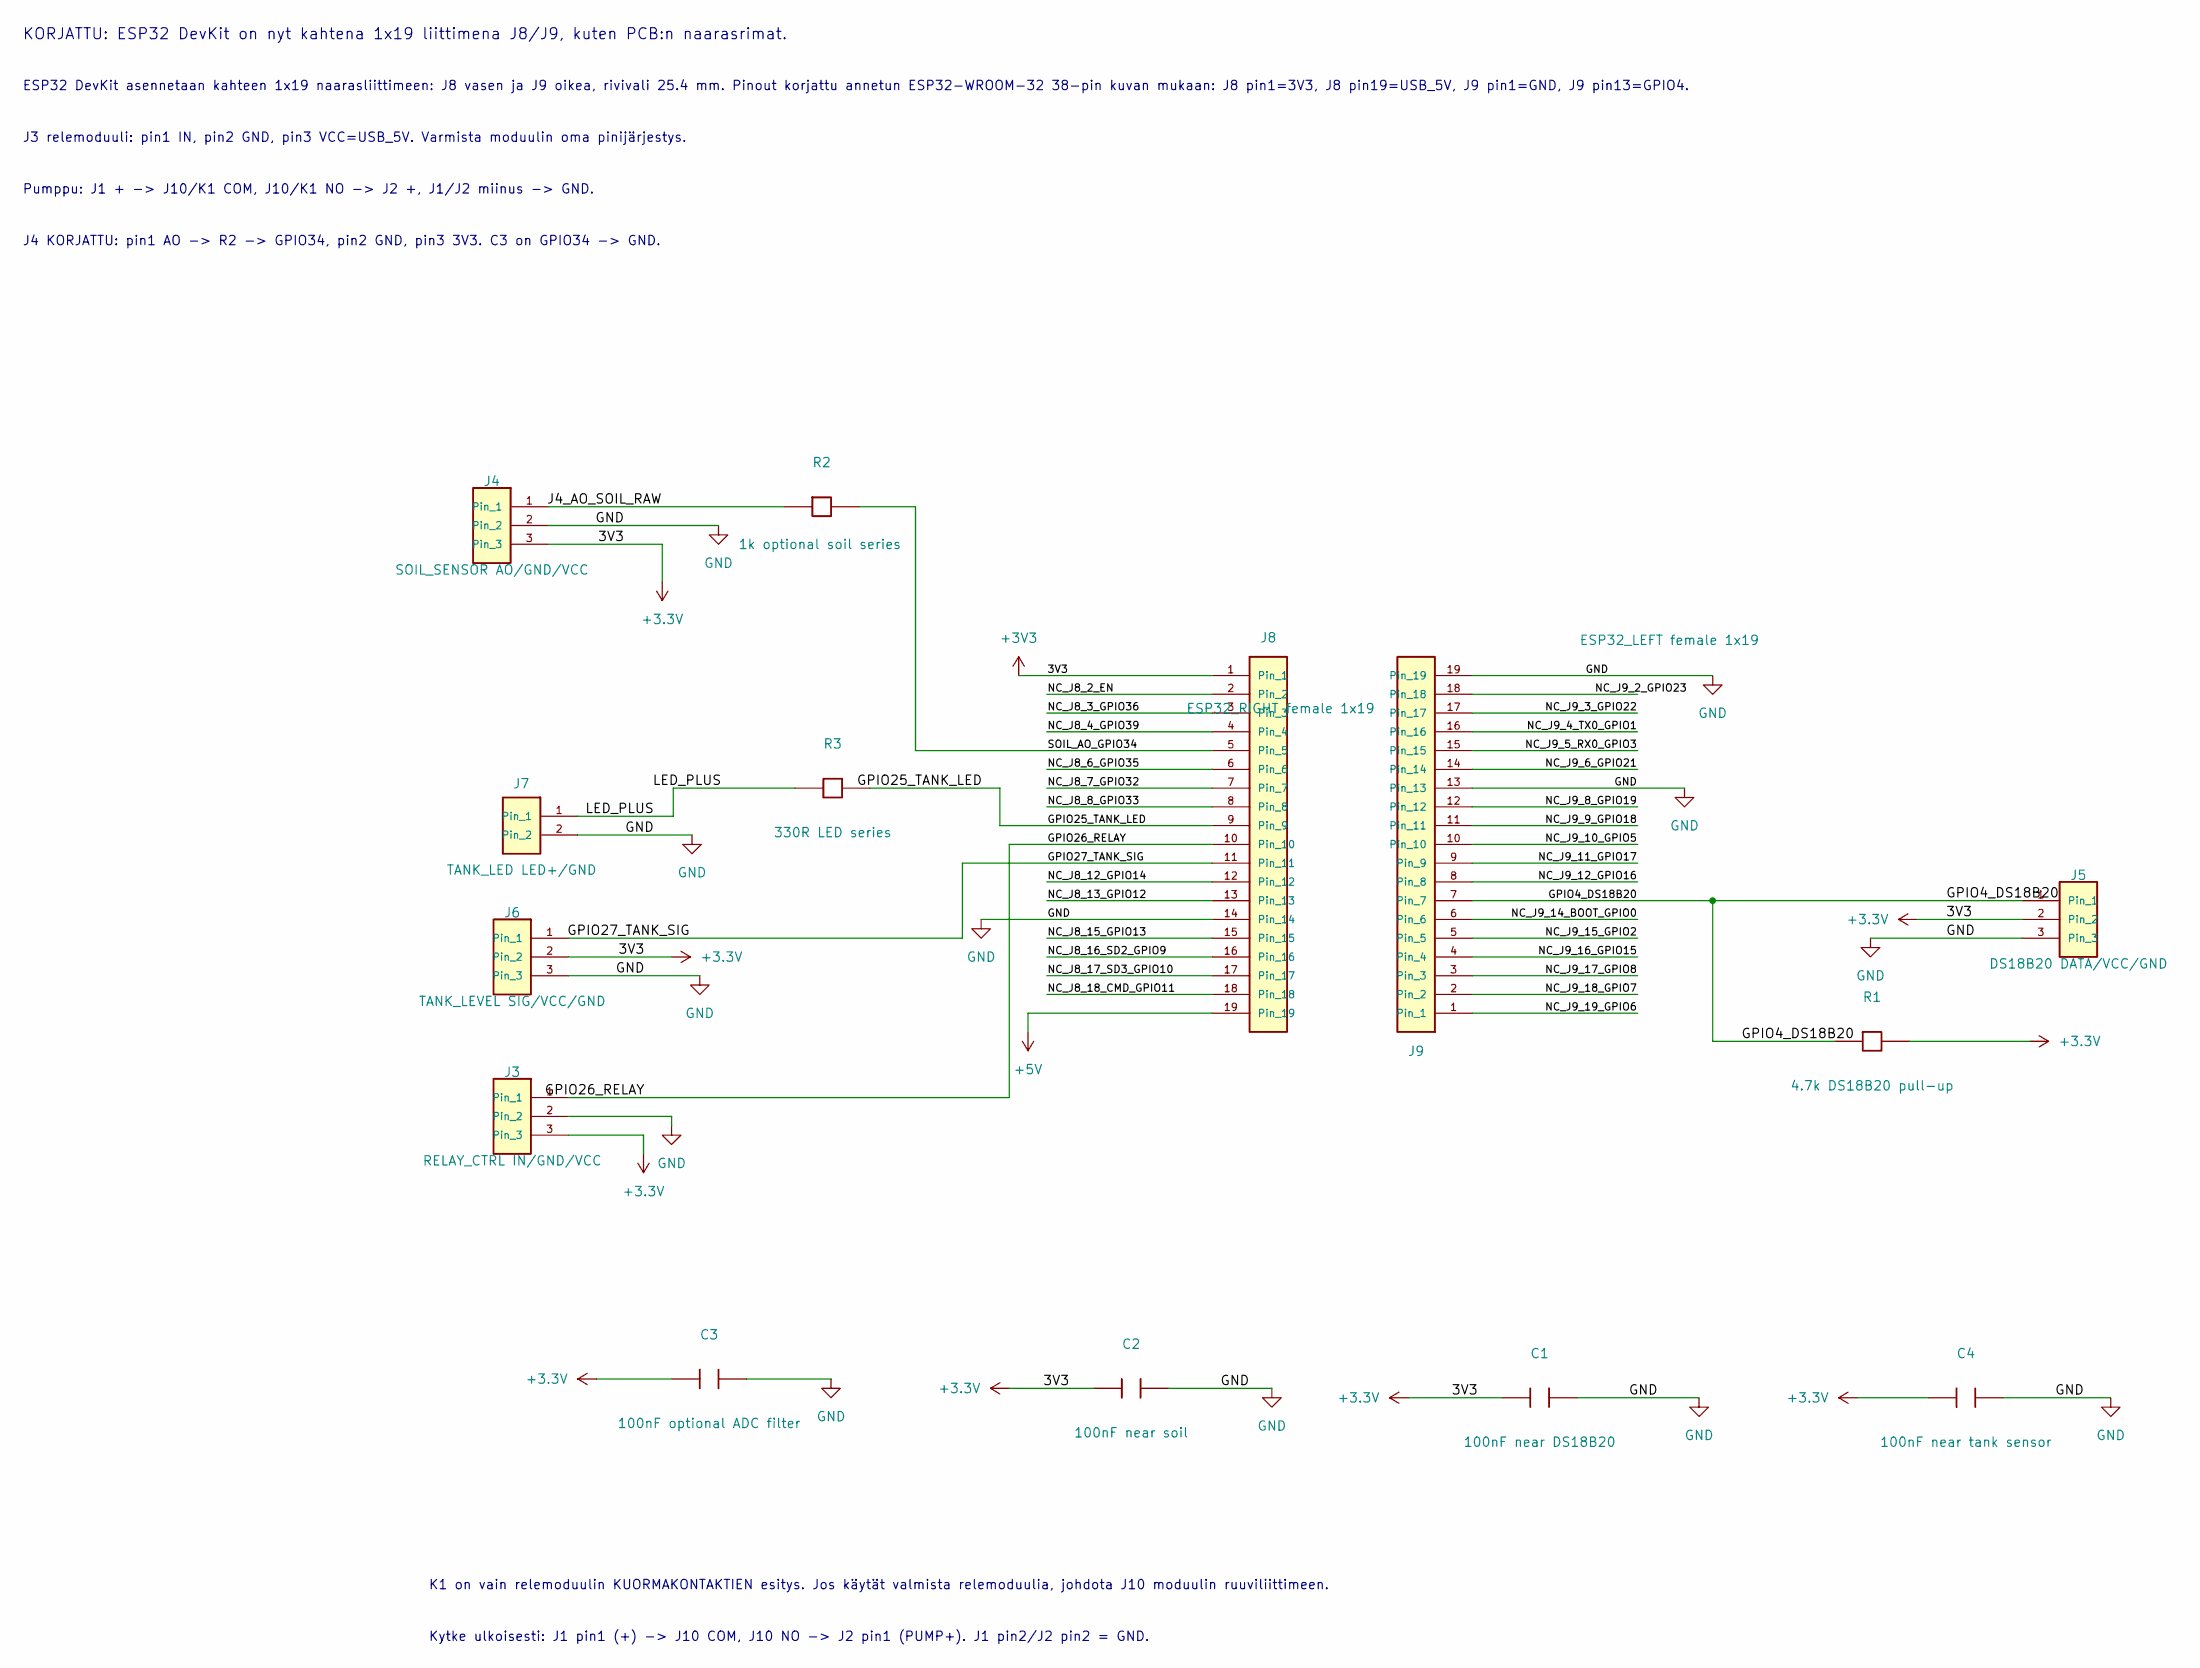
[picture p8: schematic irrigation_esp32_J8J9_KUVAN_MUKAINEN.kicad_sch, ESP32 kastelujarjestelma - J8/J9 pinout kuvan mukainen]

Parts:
C1: 100nF near DS18B20; C_Disc_D5.0mm_W2.5mm_P2.50mm
C2: 100nF near soil; C_Disc_D5.0mm_W2.5mm_P2.50mm
C3: 100nF optional ADC filter; C_Disc_D5.0mm_W2.5mm_P2.50mm
C4: 100nF near tank sensor; C_Disc_D5.0mm_W2.5mm_P2.50mm
J3: RELAY_CTRL IN/GND/VCC; PinHeader_1x03_P2.54mm_Vertical
J4: SOIL_SENSOR AO/GND/VCC; PinHeader_1x03_P2.54mm_Vertical
J5: DS18B20 DATA/VCC/GND; PinHeader_1x03_P2.54mm_Vertical
J6: TANK_LEVEL SIG/VCC/GND; PinHeader_1x03_P2.54mm_Vertical
J7: TANK_LED LED+/GND; PinHeader_1x02_P2.54mm_Vertical
J8: ESP32_LEFT female 1x19; PinSocket_1x19_P2.54mm_Vertical
J9: ESP32_RIGHT female 1x19; PinSocket_1x19_P2.54mm_Vertical
R1: 4.7k DS18B20 pull-up; R_Axial_DIN0207_L6.3mm_D2.5mm_P7.62mm_Horizontal
R2: 1k optional soil series; R_Axial_DIN0207_L6.3mm_D2.5mm_P7.62mm_Horizontal
R3: 330R LED series; R_Axial_DIN0207_L6.3mm_D2.5mm_P7.62mm_Horizontal

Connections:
+3.3V: C1.1, C2.1, C3.1, C4.1, J3.3, J4.3, J5.2, J6.2, J8.1, R1.2
+5V: J8.19
/GPIO4_DS18B20: J5.1, J9.7, R1.1
/GPIO25_TANK_LED: J8.9, R3.1
/GPIO26_RELAY: J3.1, J8.10
/GPIO27_TANK_SIG: J6.1, J8.11
/J4_AO_SOIL_RAW: J4.1, R2.1
/LED_PLUS: J7.1, R3.2
/NC_J8_2_EN: J8.2
/NC_J8_3_GPIO36: J8.3
/NC_J8_4_GPIO39: J8.4
/NC_J8_6_GPIO35: J8.6
/NC_J8_7_GPIO32: J8.7
/NC_J8_8_GPIO33: J8.8
/NC_J8_12_GPIO14: J8.12
/NC_J8_13_GPIO12: J8.13
/NC_J8_15_GPIO13: J8.15
/NC_J8_16_SD2_GPIO9: J8.16
/NC_J8_17_SD3_GPIO10: J8.17
/NC_J8_18_CMD_GPIO11: J8.18
/NC_J9_2_GPIO23: J9.18
/NC_J9_3_GPIO22: J9.17
/NC_J9_4_TX0_GPIO1: J9.16
/NC_J9_5_RX0_GPIO3: J9.15
/NC_J9_6_GPIO21: J9.14
/NC_J9_8_GPIO19: J9.12
/NC_J9_9_GPIO18: J9.11
/NC_J9_10_GPIO5: J9.10
/NC_J9_11_GPIO17: J9.9
/NC_J9_12_GPIO16: J9.8
/NC_J9_14_BOOT_GPIO0: J9.6
/NC_J9_15_GPIO2: J9.5
/NC_J9_16_GPIO15: J9.4
/NC_J9_17_GPIO8: J9.3
/NC_J9_18_GPIO7: J9.2
/NC_J9_19_GPIO6: J9.1
/SOIL_AO_GPIO34: J8.5, R2.2
GND: C1.2, C2.2, C3.2, C4.2, J3.2, J4.2, J5.3, J6.3, J7.2, J8.14, J9.13, J9.19

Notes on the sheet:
ESP32 DevKit asennetaan kahteen 1x19 naarasliittimeen: J8 vasen ja J9 oikea, rivivali 25.4 mm. Pinout korjattu annetun ESP32-WROOM-32 38-pin kuvan mukaan: J8 pin1=3V3, J8 pin19=USB_5V, J9 pin1=GND, J9 pin13=GPIO4.
J4 KORJATTU: pin1 AO -> R2 -> GPIO34, pin2 GND, pin3 3V3. C3 on GPIO34 -> GND.
Kytke ulkoisesti: J1 pin1 (+) -> J10 COM, J10 NO -> J2 pin1 (PUMP+). J1 pin2/J2 pin2 = GND.
K1 on vain relemoduulin KUORMAKONTAKTIEN esitys. Jos käytät valmista relemoduulia, johdota J10 moduulin ruuviliittimeen.
J3 relemoduuli: pin1 IN, pin2 GND, pin3 VCC=USB_5V. Varmista moduulin oma pinijärjestys.
Pumppu: J1 + -> J10/K1 COM, J10/K1 NO -> J2 +, J1/J2 miinus -> GND.
KORJATTU: ESP32 DevKit on nyt kahtena 1x19 liittimena J8/J9, kuten PCB:n naarasrimat.

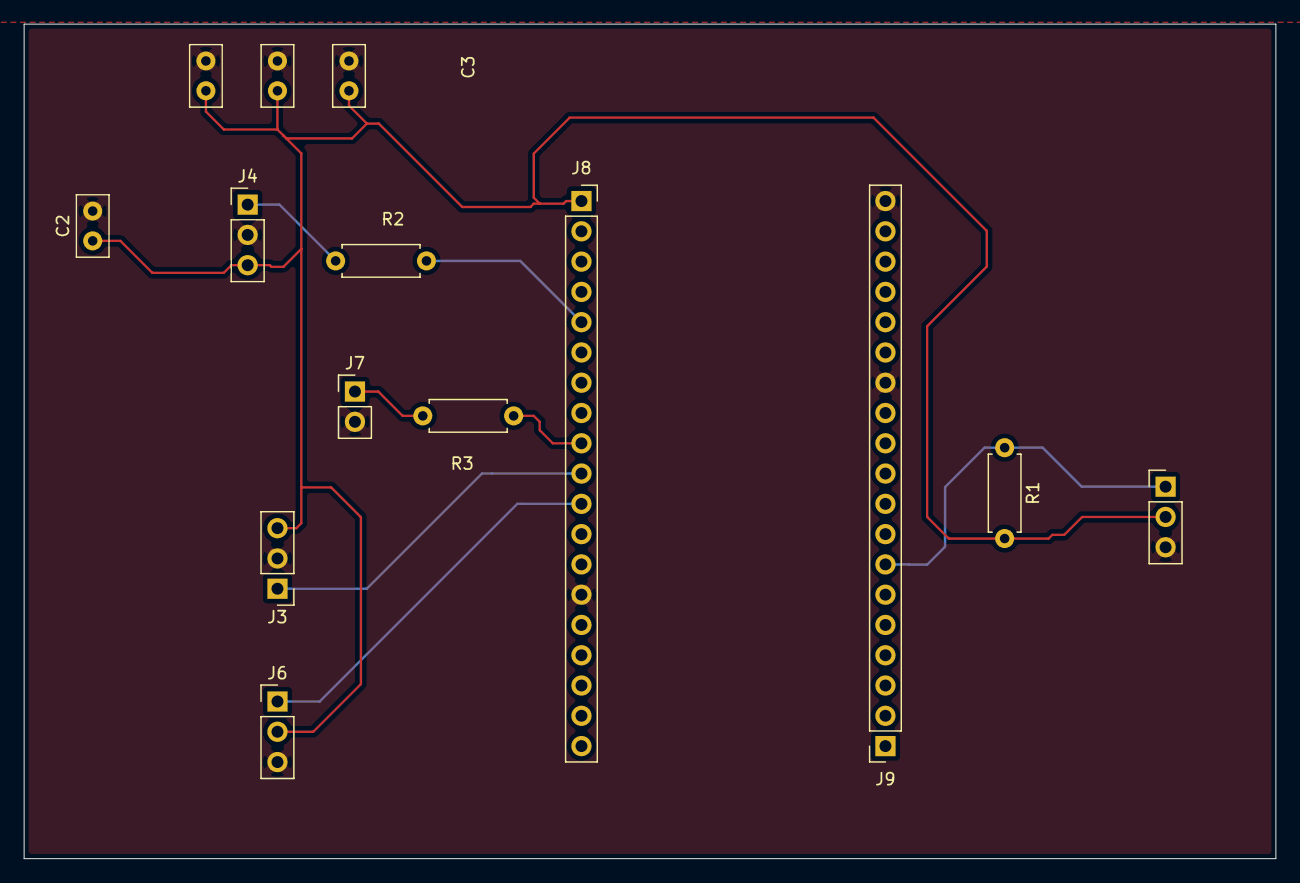
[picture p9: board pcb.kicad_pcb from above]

Board: 2 copper layers, 105.0 x 70.0 mm, 14 parts (0 on the bottom side), 9 nets.

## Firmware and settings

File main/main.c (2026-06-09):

#include <stdio.h>
#include <stdlib.h>
#include <string.h>
#include <time.h>
#include <ctype.h>
#include <stdint.h>

#include "driver/adc.h"
#include "driver/gpio.h"
#include "esp_err.h"
#include "esp_event.h"
#include "esp_log.h"
#include "esp_crt_bundle.h"
#include "esp_rom_sys.h"
#include "esp_timer.h"
#include "mqtt_client.h"
#include "esp_netif.h"
#include "esp_sntp.h"
#include "esp_wifi.h"
#include "freertos/FreeRTOS.h"
#include "freertos/event_groups.h"
#include "freertos/task.h"
#include "nvs_flash.h"

#define RELAY_GPIO GPIO_NUM_26
#define SOIL_CHANNEL ADC1_CHANNEL_6 /* GPIO34 */

#define WIFI_CONNECTED_BIT BIT0
#define WIFI_FAIL_BIT      BIT1

/* Fallbacks for stale sdkconfig in editor/intellisense */
#ifndef CONFIG_WATERING_ADC_SAMPLES
#define CONFIG_WATERING_ADC_SAMPLES 8
#endif

#ifndef CONFIG_WATERING_TEMPERATURE_ENABLED
#define CONFIG_WATERING_TEMPERATURE_ENABLED 1
#endif

#ifndef CONFIG_WATERING_TEMP_GPIO
#define CONFIG_WATERING_TEMP_GPIO 4
#endif

#ifndef CONFIG_WATERING_TEMP_READ_INTERVAL_MS
#define CONFIG_WATERING_TEMP_READ_INTERVAL_MS 10000
#endif

#ifndef CONFIG_WATERING_DRY_CONSECUTIVE_READS
#define CONFIG_WATERING_DRY_CONSECUTIVE_READS 3
#endif

#ifndef CONFIG_WATERING_MQTT_CMD_ARM_DELAY_MS
#define CONFIG_WATERING_MQTT_CMD_ARM_DELAY_MS 5000
#endif

#ifndef CONFIG_WATERING_MIN_WATERING_INTERVAL_HOURS
#define CONFIG_WATERING_MIN_WATERING_INTERVAL_HOURS 72
#endif

#ifndef CONFIG_WATERING_RELAY_SELF_TEST
#define CONFIG_WATERING_RELAY_SELF_TEST 0
#endif

#ifndef CONFIG_WATERING_RELAY_SELF_TEST_INTERVAL_MS
#define CONFIG_WATERING_RELAY_SELF_TEST_INTERVAL_MS 1000
#endif

#ifndef CONFIG_WATERING_MQTT_BROKER_URI
#define CONFIG_WATERING_MQTT_BROKER_URI "mqtt://broker.hivemq.com"
#endif

#ifndef CONFIG_WATERING_MQTT_TOPIC
#define CONFIG_WATERING_MQTT_TOPIC "watering_system/soil"
#endif

#ifndef CONFIG_WATERING_MQTT_CLIENT_ID
#define CONFIG_WATERING_MQTT_CLIENT_ID "watering-esp32"
#endif

#ifndef CONFIG_WATERING_MQTT_USERNAME
#define CONFIG_WATERING_MQTT_USERNAME ""
#endif

#ifndef CONFIG_WATERING_MQTT_PASSWORD
#define CONFIG_WATERING_MQTT_PASSWORD ""
#endif

#ifndef CONFIG_WATERING_MQTT_QOS
#define CONFIG_WATERING_MQTT_QOS 1
#endif

#ifndef CONFIG_WATERING_PUMP_DURATION_MIN_S
#define CONFIG_WATERING_PUMP_DURATION_MIN_S 8
#endif

#ifndef CONFIG_WATERING_PUMP_DURATION_MAX_S
#define CONFIG_WATERING_PUMP_DURATION_MAX_S 20
#endif

#ifndef CONFIG_WATERING_LEVEL_SENSOR_GPIO
#define CONFIG_WATERING_LEVEL_SENSOR_GPIO 27
#endif

#ifndef CONFIG_WATERING_LEVEL_SENSOR_ACTIVE_STATE
#define CONFIG_WATERING_LEVEL_SENSOR_ACTIVE_STATE 1
#endif

#ifndef CONFIG_WATERING_LEVEL_LED_GPIO
#define CONFIG_WATERING_LEVEL_LED_GPIO 25
#endif

#ifndef CONFIG_WATERING_LEVEL_LED_ACTIVE_STATE
#define CONFIG_WATERING_LEVEL_LED_ACTIVE_STATE 1
#endif

#ifndef CONFIG_WATERING_LEVEL_LED_ON_WHEN_LOW
#define CONFIG_WATERING_LEVEL_LED_ON_WHEN_LOW 1
#endif

#ifndef CONFIG_WATERING_MOISTURE_WET_ADC
#define CONFIG_WATERING_MOISTURE_WET_ADC 1500
#endif

#ifndef CONFIG_WATERING_MOISTURE_DRY_ADC
#define CONFIG_WATERING_MOISTURE_DRY_ADC 3200
#endif

#ifndef CONFIG_WATERING_MQTT_TOPIC_MOISTURE_RAW
#define CONFIG_WATERING_MQTT_TOPIC_MOISTURE_RAW "watering_system/soil/raw"
#endif

#ifndef CONFIG_WATERING_MQTT_TOPIC_MOISTURE_PERCENT
#define CONFIG_WATERING_MQTT_TOPIC_MOISTURE_PERCENT "watering_system/soil/dry_percent"
#endif

#ifndef CONFIG_WATERING_MQTT_TOPIC_TEMPERATURE_C
#define CONFIG_WATERING_MQTT_TOPIC_TEMPERATURE_C "watering_system/temperature/outdoor_c"
#endif

#ifndef CONFIG_WATERING_MQTT_TOPIC_CMD_PUMP_DURATION_S
#define CONFIG_WATERING_MQTT_TOPIC_CMD_PUMP_DURATION_S "watering_system/cmd/pump_duration_s"
#endif

#ifndef CONFIG_WATERING_MQTT_TOPIC_CMD_PUMP_MANUAL
#define CONFIG_WATERING_MQTT_TOPIC_CMD_PUMP_MANUAL "watering_system/cmd/pump_manual"
#endif

#ifndef CONFIG_WATERING_MQTT_TOPIC_CMD_PUMP_ENABLE
#define CONFIG_WATERING_MQTT_TOPIC_CMD_PUMP_ENABLE "watering_system/cmd/pump_enable"
#endif

#ifndef CONFIG_WATERING_MQTT_TOPIC_CMD_MEASURE_NOW
#define CONFIG_WATERING_MQTT_TOPIC_CMD_MEASURE_NOW "watering_system/cmd/measure_now"
#endif

#ifndef CONFIG_WATERING_MQTT_TOPIC_STATUS_PUMP_DURATION_S
#define CONFIG_WATERING_MQTT_TOPIC_STATUS_PUMP_DURATION_S "watering_system/status/pump_duration_s"
#endif

#ifndef CONFIG_WATERING_MQTT_TOPIC_STATUS_PUMP_ENABLE
#define CONFIG_WATERING_MQTT_TOPIC_STATUS_PUMP_ENABLE "watering_system/status/pump_enable"
#endif

#ifndef CONFIG_WATERING_MQTT_TOPIC_STATUS_PUMP_RUNNING
#define CONFIG_WATERING_MQTT_TOPIC_STATUS_PUMP_RUNNING "watering_system/status/pump_running"
#endif

#ifndef CONFIG_WATERING_MQTT_TOPIC_STATUS_TANK_LEVEL
#define CONFIG_WATERING_MQTT_TOPIC_STATUS_TANK_LEVEL "watering_system/status/tank_level"
#endif

#ifndef CONFIG_WATERING_MQTT_TOPIC_STATUS_TANK_LEVEL_RAW
#define CONFIG_WATERING_MQTT_TOPIC_STATUS_TANK_LEVEL_RAW "watering_system/status/tank_level_raw"
#endif

#ifndef GPIO_NUM_NC
#define GPIO_NUM_NC ((gpio_num_t)-1)
#endif

static const char *TAG = "watering";
static EventGroupHandle_t s_wifi_event_group;
static int s_retry_num;
static esp_mqtt_client_handle_t s_mqtt_client;
static int s_mqtt_connected;
static time_t s_last_watering_ts;
static int s_pump_enabled = 1;
static int s_pump_running;
static int s_pump_duration_ms = CONFIG_WATERING_PUMP_ON_MS;
static int s_manual_watering_requests;
static int s_manual_measure_requests;
static float s_last_temperature_c;
static int s_last_temperature_valid;
static gpio_num_t s_temp_gpio = GPIO_NUM_NC;
static int s_temperature_gpio_ready;
static gpio_num_t s_level_sensor_gpio = GPIO_NUM_NC;
static int s_level_sensor_ready;
static int s_tank_level_has_water = -1;
static gpio_num_t s_level_led_gpio = GPIO_NUM_NC;
static int s_level_led_ready;
static int64_t s_mqtt_connected_since_us;
static portMUX_TYPE s_state_lock = portMUX_INITIALIZER_UNLOCKED;

static int mqtt_publish_message(const char *topic, const char *payload, int retain);
static void mqtt_publish_int_message(const char *topic, int value, int retain);

static void set_last_watering_ts(time_t value)
{
    taskENTER_CRITICAL(&s_state_lock);
    s_last_watering_ts = value;
    taskEXIT_CRITICAL(&s_state_lock);
}

static time_t get_last_watering_ts(void)
{
    time_t value;

    taskENTER_CRITICAL(&s_state_lock);
    value = s_last_watering_ts;
    taskEXIT_CRITICAL(&s_state_lock);

    return value;
}

static void set_last_temperature(float value, int valid)
{
    taskENTER_CRITICAL(&s_state_lock);
    s_last_temperature_c = value;
    s_last_temperature_valid = valid ? 1 : 0;
    taskEXIT_CRITICAL(&s_state_lock);
}

static int get_last_temperature(float *out_value)
{
    int valid;
    float value;

    taskENTER_CRITICAL(&s_state_lock);
    value = s_last_temperature_c;
    valid = s_last_temperature_valid;
    taskEXIT_CRITICAL(&s_state_lock);

    if (valid && out_value != NULL) {
        *out_value = value;
    }
    return valid;
}

static void set_mqtt_connected_since_us(int64_t timestamp_us)
{
    taskENTER_CRITICAL(&s_state_lock);
    s_mqtt_connected_since_us = timestamp_us;
    taskEXIT_CRITICAL(&s_state_lock);
}

static int64_t get_mqtt_connected_since_us(void)
{
    int64_t timestamp_us;

    taskENTER_CRITICAL(&s_state_lock);
    timestamp_us = s_mqtt_connected_since_us;
    taskEXIT_CRITICAL(&s_state_lock);

    return timestamp_us;
}

static void set_tank_level_has_water(int has_water)
{
    int value = has_water > 0 ? 1 : (has_water == 0 ? 0 : -1);

    taskENTER_CRITICAL(&s_state_lock);
    s_tank_level_has_water = value;
    taskEXIT_CRITICAL(&s_state_lock);
}

static int get_tank_level_has_water(void)
{
    int has_water;

    taskENTER_CRITICAL(&s_state_lock);
    has_water = s_tank_level_has_water;
    taskEXIT_CRITICAL(&s_state_lock);

    return has_water;
}

static int clamp_int(int value, int min_value, int max_value)
{
    if (value < min_value) {
        return min_value;
    }
    if (value > max_value) {
        return max_value;
    }
    return value;
}

static void set_pump_enabled(int enabled)
{
    taskENTER_CRITICAL(&s_state_lock);
    s_pump_enabled = enabled ? 1 : 0;
    taskEXIT_CRITICAL(&s_state_lock);
}

static int get_pump_enabled(void)
{
    int enabled;

    taskENTER_CRITICAL(&s_state_lock);
    enabled = s_pump_enabled;
    taskEXIT_CRITICAL(&s_state_lock);

    return enabled;
}

static void set_pump_running(int running)
{
    taskENTER_CRITICAL(&s_state_lock);
    s_pump_running = running ? 1 : 0;
    taskEXIT_CRITICAL(&s_state_lock);
}

static int get_pump_running(void)
{
    int running;

    taskENTER_CRITICAL(&s_state_lock);
    running = s_pump_running;
    taskEXIT_CRITICAL(&s_state_lock);

    return running;
}

static int get_pump_duration_ms(void)
{
    int duration_ms;

    taskENTER_CRITICAL(&s_state_lock);
    duration_ms = s_pump_duration_ms;
    taskEXIT_CRITICAL(&s_state_lock);

    return duration_ms;
}

static void set_pump_duration_ms(int duration_ms)
{
    int min_ms = CONFIG_WATERING_PUMP_DURATION_MIN_S * 1000;
    int max_ms = CONFIG_WATERING_PUMP_DURATION_MAX_S * 1000;
    if (max_ms < min_ms) {
        max_ms = min_ms;
    }

    taskENTER_CRITICAL(&s_state_lock);
    s_pump_duration_ms = clamp_int(duration_ms, min_ms, max_ms);
    taskEXIT_CRITICAL(&s_state_lock);
}

static void queue_manual_watering_request(void)
{
    taskENTER_CRITICAL(&s_state_lock);
    if (s_manual_watering_requests < 10) {
        s_manual_watering_requests++;
    }
    taskEXIT_CRITICAL(&s_state_lock);
}

static int consume_manual_watering_request(void)
{
    int has_request = 0;

    taskENTER_CRITICAL(&s_state_lock);
    if (s_manual_watering_requests > 0) {
        s_manual_watering_requests--;
        has_request = 1;
    }
    taskEXIT_CRITICAL(&s_state_lock);

    return has_request;
}

static void queue_manual_measure_request(void)
{
    taskENTER_CRITICAL(&s_state_lock);
    if (s_manual_measure_requests < 10) {
        s_manual_measure_requests++;
    }
    taskEXIT_CRITICAL(&s_state_lock);
}

static int consume_manual_measure_request(void)
{
    int has_request = 0;

    taskENTER_CRITICAL(&s_state_lock);
    if (s_manual_measure_requests > 0) {
        s_manual_measure_requests--;
        has_request = 1;
    }
    taskEXIT_CRITICAL(&s_state_lock);

    return has_request;
}

static void relay_init(void)
{
    gpio_config_t io_conf = {
        .pin_bit_mask = (1ULL << RELAY_GPIO),
        .mode = GPIO_MODE_OUTPUT,
        .pull_up_en = GPIO_PULLUP_DISABLE,
        .pull_down_en = GPIO_PULLDOWN_DISABLE,
        .intr_type = GPIO_INTR_DISABLE,
    };
    ESP_ERROR_CHECK(gpio_config(&io_conf));

    /* Active-low relay modules are common: HIGH = OFF, LOW = ON */
    ESP_ERROR_CHECK(gpio_set_level(RELAY_GPIO, 1));
}

static void soil_adc_init(void)
{
    ESP_ERROR_CHECK(adc1_config_width(ADC_WIDTH_BIT_12));
    ESP_ERROR_CHECK(adc1_config_channel_atten(SOIL_CHANNEL, ADC_ATTEN_DB_11));
}

static int soil_read(void)
{
    return adc1_get_raw(SOIL_CHANNEL);
}

static int soil_read_average(void)
{
    int sum = 0;

    for (int i = 0; i < CONFIG_WATERING_ADC_SAMPLES; i++) {
        sum += soil_read();
        vTaskDelay(pdMS_TO_TICKS(20));
    }

    return sum / CONFIG_WATERING_ADC_SAMPLES;
}

static const char *tank_level_to_text(int has_water)
{
    if (has_water > 0) {
        return "FULL";
    }
    if (has_water == 0) {
        return "LOW";
    }
    return "UNKNOWN";
}

static int tank_level_sensor_read_has_water(void)
{
    int raw_level;
    int active_level = CONFIG_WATERING_LEVEL_SENSOR_ACTIVE_STATE ? 1 : 0;

    if (!s_level_sensor_ready) {
        return -1;
    }

    raw_level = gpio_get_level(s_level_sensor_gpio) ? 1 : 0;
    return raw_level == active_level ? 1 : 0;
}

static void mqtt_publish_tank_level_state(int has_water)
{
    mqtt_publish_message(CONFIG_WATERING_MQTT_TOPIC_STATUS_TANK_LEVEL,
                         tank_level_to_text(has_water),
                         1);
    mqtt_publish_int_message(CONFIG_WATERING_MQTT_TOPIC_STATUS_TANK_LEVEL_RAW,
                             has_water,
                             1);
}

static void level_led_apply_from_tank_level(int has_water)
{
    int should_on;
    int gpio_level;
    esp_err_t err;

    if (!s_level_led_ready || has_water < 0) {
        return;
    }

    should_on = CONFIG_WATERING_LEVEL_LED_ON_WHEN_LOW ? (has_water == 0) : (has_water > 0);
    gpio_level = should_on ? (CONFIG_WATERING_LEVEL_LED_ACTIVE_STATE ? 1 : 0)
                           : (CONFIG_WATERING_LEVEL_LED_ACTIVE_STATE ? 0 : 1);

    err = gpio_set_level(s_level_led_gpio, gpio_level);
    if (err != ESP_OK) {
        ESP_LOGW(TAG, "Failed to set level LED GPIO%d (err=0x%x)", s_level_led_gpio, err);
    }
}

static int tank_level_refresh_state(int force_publish)
{
    int has_water = tank_level_sensor_read_has_water();
    int previous = get_tank_level_has_water();

    if (has_water < 0) {
        if (force_publish || previous != -1) {
            set_tank_level_has_water(-1);
            mqtt_publish_tank_level_state(-1);
        }
        return -1;
    }

    set_tank_level_has_water(has_water);
    level_led_apply_from_tank_level(has_water);

    if (force_publish || has_water != previous) {
        ESP_LOGI(TAG, "Tank level state: %s", tank_level_to_text(has_water));
        mqtt_publish_tank_level_state(has_water);
    }

    return has_water;
}

static void tank_level_sensor_init(void)
{
    gpio_config_t io_conf = {0};
    int initial_has_water;

    if (!GPIO_IS_VALID_GPIO(CONFIG_WATERING_LEVEL_SENSOR_GPIO)) {
        ESP_LOGW(TAG, "Invalid tank level sensor GPIO: %d", CONFIG_WATERING_LEVEL_SENSOR_GPIO);
        return;
    }

    s_level_sensor_gpio = (gpio_num_t)CONFIG_WATERING_LEVEL_SENSOR_GPIO;
    io_conf.pin_bit_mask = (1ULL << s_level_sensor_gpio);
    io_conf.mode = GPIO_MODE_INPUT;
    io_conf.pull_up_en = GPIO_PULLUP_ENABLE;
    io_conf.pull_down_en = GPIO_PULLDOWN_DISABLE;
    io_conf.intr_type = GPIO_INTR_DISABLE;

    ESP_ERROR_CHECK(gpio_config(&io_conf));
    s_level_sensor_ready = 1;
    initial_has_water = tank_level_sensor_read_has_water();
    set_tank_level_has_water(initial_has_water);

    ESP_LOGI(TAG,
             "Tank level sensor on GPIO%d (active_state=%d), initial=%s",
             CONFIG_WATERING_LEVEL_SENSOR_GPIO,
             CONFIG_WATERING_LEVEL_SENSOR_ACTIVE_STATE ? 1 : 0,
             tank_level_to_text(initial_has_water));
}

static void level_led_init(void)
{
    gpio_config_t io_conf = {0};
    int initial_level;
    esp_err_t err;

    if (!GPIO_IS_VALID_OUTPUT_GPIO(CONFIG_WATERING_LEVEL_LED_GPIO)) {
        ESP_LOGW(TAG, "Invalid level LED GPIO: %d", CONFIG_WATERING_LEVEL_LED_GPIO);
        return;
    }

    s_level_led_gpio = (gpio_num_t)CONFIG_WATERING_LEVEL_LED_GPIO;
    io_conf.pin_bit_mask = (1ULL << s_level_led_gpio);
    io_conf.mode = GPIO_MODE_OUTPUT;
    io_conf.pull_up_en = GPIO_PULLUP_DISABLE;
    io_conf.pull_down_en = GPIO_PULLDOWN_DISABLE;
    io_conf.intr_type = GPIO_INTR_DISABLE;

    ESP_ERROR_CHECK(gpio_config(&io_conf));
    s_level_led_ready = 1;
    initial_level = CONFIG_WATERING_LEVEL_LED_ACTIVE_STATE ? 0 : 1;
    err = gpio_set_level(s_level_led_gpio, initial_level);
    if (err != ESP_OK) {
        ESP_LOGW(TAG, "Failed to initialize level LED GPIO%d (err=0x%x)", s_level_led_gpio, err);
        return;
    }
    ESP_LOGI(TAG,
             "Level LED ready on GPIO%d (active_state=%d, on_when_low=%d)",
             CONFIG_WATERING_LEVEL_LED_GPIO,
             CONFIG_WATERING_LEVEL_LED_ACTIVE_STATE ? 1 : 0,
             CONFIG_WATERING_LEVEL_LED_ON_WHEN_LOW ? 1 : 0);
}

static void onewire_drive_low(void)
{
    ESP_ERROR_CHECK(gpio_set_level(s_temp_gpio, 0));
}

static void onewire_release_line(void)
{
    ESP_ERROR_CHECK(gpio_set_level(s_temp_gpio, 1));
}

static int ds18b20_reset_and_presence(void)
{
    int presence = 0;

    onewire_drive_low();
    esp_rom_delay_us(480);
    onewire_release_line();
    esp_rom_delay_us(70);
    presence = (gpio_get_level(s_temp_gpio) == 0);
    esp_rom_delay_us(410);

    return presence;
}

static void ds18b20_write_bit(int bit_value)
{
    onewire_drive_low();
    if (bit_value) {
        esp_rom_delay_us(6);
        onewire_release_line();
        esp_rom_delay_us(64);
    } else {
        esp_rom_delay_us(60);
        onewire_release_line();
        esp_rom_delay_us(10);
    }
}

static int ds18b20_read_bit(void)
{
    int bit_value;

    onewire_drive_low();
    esp_rom_delay_us(3);
    onewire_release_line();
    esp_rom_delay_us(10);
    bit_value = gpio_get_level(s_temp_gpio);
    esp_rom_delay_us(53);

    return bit_value;
}

static void ds18b20_write_byte(uint8_t value)
{
    for (int i = 0; i < 8; i++) {
        ds18b20_write_bit((value >> i) & 0x1);
    }
}

static uint8_t ds18b20_read_byte(void)
{
    uint8_t value = 0;

    for (int i = 0; i < 8; i++) {
        if (ds18b20_read_bit()) {
            value |= (uint8_t)(1U << i);
        }
    }

    return value;
}

static uint8_t ds18b20_crc8(const uint8_t *data, size_t len)
{
    uint8_t crc = 0;

    for (size_t i = 0; i < len; i++) {
        uint8_t inbyte = data[i];
        for (int bit = 0; bit < 8; bit++) {
            uint8_t mix = (crc ^ inbyte) & 0x01;
            crc >>= 1;
            if (mix) {
                crc ^= 0x8C;
            }
            inbyte >>= 1;
        }
    }

    return crc;
}

static void temperature_sensor_init(void)
{
#if CONFIG_WATERING_TEMPERATURE_ENABLED
    gpio_config_t io_conf = {0};

    if (!GPIO_IS_VALID_OUTPUT_GPIO(CONFIG_WATERING_TEMP_GPIO)) {
        ESP_LOGW(TAG, "Invalid DS18B20 GPIO: %d", CONFIG_WATERING_TEMP_GPIO);
        return;
    }

    s_temp_gpio = (gpio_num_t)CONFIG_WATERING_TEMP_GPIO;
    io_conf.pin_bit_mask = (1ULL << s_temp_gpio);
    io_conf.mode = GPIO_MODE_INPUT_OUTPUT_OD;
    io_conf.pull_up_en = GPIO_PULLUP_ENABLE;
    io_conf.pull_down_en = GPIO_PULLDOWN_DISABLE;
    io_conf.intr_type = GPIO_INTR_DISABLE;

    ESP_ERROR_CHECK(gpio_config(&io_conf));
    onewire_release_line();
    s_temperature_gpio_ready = 1;

    if (ds18b20_reset_and_presence()) {
        ESP_LOGI(TAG, "DS18B20 detected on GPIO%d", CONFIG_WATERING_TEMP_GPIO);
    } else {
        ESP_LOGW(TAG, "No DS18B20 presence pulse on GPIO%d", CONFIG_WATERING_TEMP_GPIO);
    }
    ESP_LOGI(TAG, "Use external 4.7k pull-up between DS18B20 DATA and 3V3");
#else
    ESP_LOGI(TAG, "DS18B20 support disabled");
#endif
}

static esp_err_t ds18b20_read_celsius(float *out_celsius)
{
    uint8_t scratchpad[9];

    if (out_celsius == NULL || !s_temperature_gpio_ready) {
        return ESP_ERR_INVALID_STATE;
    }

    if (!ds18b20_reset_and_presence()) {
        return ESP_ERR_NOT_FOUND;
    }
    ds18b20_write_byte(0xCC); /* Skip ROM, single device on bus */
    ds18b20_write_byte(0x44); /* Convert T */

    vTaskDelay(pdMS_TO_TICKS(750));

    if (!ds18b20_reset_and_presence()) {
        return ESP_ERR_TIMEOUT;
    }
    ds18b20_write_byte(0xCC); /* Skip ROM */
    ds18b20_write_byte(0xBE); /* Read scratchpad */

    for (int i = 0; i < 9; i++) {
        scratchpad[i] = ds18b20_read_byte();
    }

    if (ds18b20_crc8(scratchpad, 8) != scratchpad[8]) {
        return ESP_FAIL;
    }

    int16_t raw_temp = (int16_t)((scratchpad[1] << 8) | scratchpad[0]);
    *out_celsius = (float)raw_temp / 16.0f;
    return ESP_OK;
}

static void wifi_event_handler(void *arg, esp_event_base_t event_base, int32_t event_id, void *event_data)
{
    if (event_base == WIFI_EVENT && event_id == WIFI_EVENT_STA_START) {
        ESP_ERROR_CHECK(esp_wifi_connect());
        return;
    }

    if (event_base == WIFI_EVENT && event_id == WIFI_EVENT_STA_DISCONNECTED) {
        if (s_retry_num < CONFIG_WATERING_WIFI_MAXIMUM_RETRY) {
            ESP_ERROR_CHECK(esp_wifi_connect());
            s_retry_num++;
            ESP_LOGI(TAG, "WiFi reconnecting... (%d/%d)", s_retry_num, CONFIG_WATERING_WIFI_MAXIMUM_RETRY);
        } else {
            xEventGroupSetBits(s_wifi_event_group, WIFI_FAIL_BIT);
        }
        return;
    }

    if (event_base == IP_EVENT && event_id == IP_EVENT_STA_GOT_IP) {
        ip_event_got_ip_t *event = (ip_event_got_ip_t *)event_data;
        ESP_LOGI(TAG, "WiFi connected, IP: " IPSTR, IP2STR(&event->ip_info.ip));
        s_retry_num = 0;
        xEventGroupSetBits(s_wifi_event_group, WIFI_CONNECTED_BIT);
    }
}
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
void app_main(void)
{
    int check_interval_ms = clamp_int(CONFIG_WATERING_CHECK_INTERVAL_MS, 1000, 86400000);

    set_pump_enabled(1);
    set_pump_running(0);
    set_pump_duration_ms(CONFIG_WATERING_PUMP_ON_MS);

    relay_init();
    level_led_init();
    tank_level_sensor_init();
    tank_level_refresh_state(1);

#if CONFIG_WATERING_RELAY_SELF_TEST
    xTaskCreate(relay_self_test_task, "relay_self_test_task", 3072, NULL, 5, NULL);
    return;
#endif

    soil_adc_init();
    temperature_sensor_init();
    wifi_init_sta();
    time_init();
    mqtt_init();
    ESP_LOGI(TAG, "Pump duration initialized to %d s", get_pump_duration_ms() / 1000);
    ESP_LOGI(TAG, "Moisture check interval is %d s (%d min)",
             check_interval_ms / 1000, check_interval_ms / 60000);
    ESP_LOGI(TAG, "MQTT command arm-delay is %d ms", CONFIG_WATERING_MQTT_CMD_ARM_DELAY_MS);

    xTaskCreate(watering_task, "watering_task", 3072, NULL, 5, NULL);
#if CONFIG_WATERING_TEMPERATURE_ENABLED
    xTaskCreate(temperature_task, "temperature_task", 4096, NULL, 5, NULL);
#endif
}

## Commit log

2026-06-09 Initial watering system project
    [BOM_irrigation_esp32_REAL_components_J8J9_FINAL_FIXED.csv, esp32_kastelu_kotelo.scad, irrigation_esp32_J8J9_KUVAN_MUKAINEN.kicad_pcb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]
2026-06-09 Fix GitHub and KiCad documentation
